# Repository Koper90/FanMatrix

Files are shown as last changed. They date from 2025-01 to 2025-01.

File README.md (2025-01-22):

# FanMatrix



This board was created out of necessity, as I found myself needing more fan and thermistor ports for my own 3D printers. It's perfect for expanding cooling systems, temperature monitoring, and fan control setups in Klipper-based 3D printers, with minimal additional cost.

This repository contains the design files and firmware for a low-cost PCB-based port expander. It is specifically designed to run Klipper firmware for controlling cooling and sensor peripherals in 3D printers. The board takes in 24V DC and steps it down to 12V and 5V, each capable of delivering up to 1A of current, making it ideal for controlling fans and sensors.

### Key features include:

- 5 PWM fan outputs with selectable fan voltage via jumper (12V or 5V).
- 4 tacho fan outputs to monitor fan RPM with selectable fan voltage via jumper (12V or 5V).
- 9 thermistor inputs for temperature monitoring.
- STM32 32-bit ARM Cortex M0 microcontroller for efficient processing and control.
- A serial connection via USB-C allows easy communication with external systems.
- 3 additional ports available for expansion with extra peripherals.

Designed to run Klipper firmware for seamless integration with 3D printing systems.
Designed with low cost in mind for accessible integration into projects.

### Mounting

Mounts are located in the CAD folder.

### Connectors

All the connectors are JST PH 2.54.

### Interactive BOM

[FanMatrix BOM](https://htmlpreview.github.io/?https://github.com/Koper90/FanMatrix/blob/main/KiCad/ibom.html)

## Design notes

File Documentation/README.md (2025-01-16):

This document outlines the common features of the board that you are likely to use.

## Main Features
annotely_image (1)

The board operates on a 24V DC power supply and includes the following inputs and outputs (I/O):

- 5 PWM 4-pin fan outputs
- 4 ground-switched fan outputs with tacho feedback
- 9 thermistor inputs for temperature sensing

Each fan output is equipped with a voltage selector, allowing the user to choose between 5V, 12V, or 24V DC depending on the requirements of the connected fan.

The board also features a fuse slot, and it is recommended to use a 3 AMP automotive fuse to protect the circuit from overcurrent conditions.

## Voltage selector for fan outputs

To set the appropriate voltage for the fan output, use the jumper and place it in the correct position on the voltage pin selector. The board is marked with the available voltages. For example, in the image below, putting the jumper in the orientation shown within the red rectangle selects 24V for the fan output.

Ensure that the jumper is securely placed and matches the required voltage for your device before powering on the system.


## LED indicator

LED indicators for the 5V and 12V DC busbars, which are used to verify whether 5V and 12V power is available.

## Boot and reset keys

This boot button needs to be pressed to put the board in DFU mode to flash it with the klipper firmware. The board will show up as "Device in DFU Mode" to ```lsusb``` and then should show up in ```dfu-util --list```

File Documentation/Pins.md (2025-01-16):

### Fan and Thermistor Pin Assignments for FanMatrix Board

#### 4-Pin PWM Fan Pin Assignments
The following pins are used for controlling 4-pin PWM fans. Each fan has a designated PWM signal and a tachometer (TACHO) pin:

- **FAN 1**:  
  - PWM: `PB10`
  - TACHO: `PB11`

- **FAN 2**:  
  - PWM: `PB1`
  - TACHO: `PB2`

- **FAN 3**:  
  - PWM: `PB0`
  - TACHO: `PA7`

- **FAN 4**:  
  - PWM: `PA6`
  - TACHO: `PA5`

- **FAN 5**:  
  - PWM: `PA4`
  - TACHO: `PA3`

#### 3-Pin Fan Pin Assignments
These pins are used for 3-pin fans, where PWM is tied to GND, and a tachometer is provided for speed monitoring:

- **FAN 1**:  
  - PWM: `PA0`
  - TACHO: `PA1`

- **FAN 2**:  
  - PWM: `PB12`
  - TACHO: `PA2`

- **FAN 3**:  
  - PWM: `PB15`
  - TACHO: `PB14`

- **FAN 4**:  
  - PWM: `PA9`
  - TACHO: `PA8`

#### Thermistor Pin Assignments
The thermistor inputs are assigned to the following pins:

- **Therm0**: `PB9`
- **Therm1**: `PB8`
- **Therm2**: `PB7`
- **Therm3**: `PB6`
- **Therm4**: `PB5`
- **Therm5**: `PB4`
- **Therm6**: `PB3`
- **Therm7**: `PA15`
- **Therm8**: `PA14`

### Usage Notes
- Ensure that all connections are properly made according to the above pin assignments.
- The 4-pin fans use separate PWM and tachometer pins for precise speed control and monitoring.
- For 3-pin fans, PWM signals are tied to GND, so speed is controlled by manipulating GND, but tachometer readings are still available for monitoring.
- Thermistor inputs can be used to monitor temperature readings for various zones or components.

This pin documentation should serve as a reference for configuring and wiring the FanMatrix board.

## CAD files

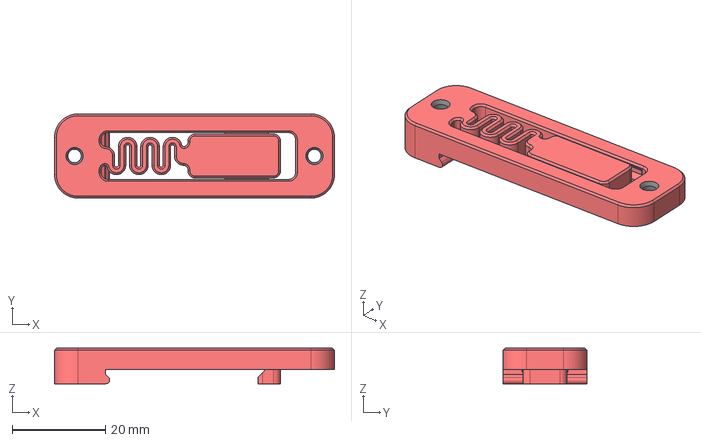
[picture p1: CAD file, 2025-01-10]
CAD/Stiffer_DinMount_M3.stp
59.9 x 18.0 x 7.60 mm

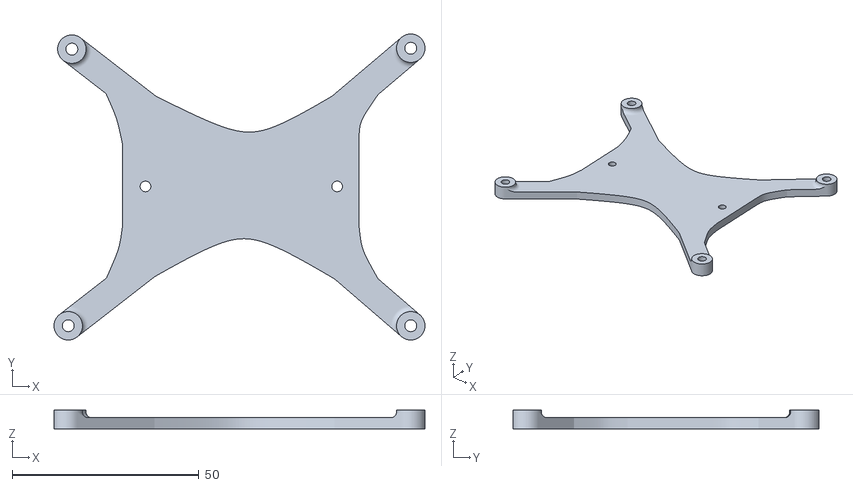
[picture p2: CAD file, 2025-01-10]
CAD/FanMatrix_Mount.stl
99.3 x 81.9 x 5.00

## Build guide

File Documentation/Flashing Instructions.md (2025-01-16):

Here’s a summarized and clarified version of the flashing instructions for ease of use:

---

### Flashing the Board for Klipper

1. **Connect Hardware**  
   - Attach the board to the Raspberry Pi via USB.  
   - Ensure either the **5V jumper** is connected or **24V power** is supplied to the board.

2. **Access Raspberry Pi**  
   - Connect to the Raspberry Pi via SSH.

3. **Enter DFU Mode**  
   - Press and hold the **Boot** button.  
   - While holding **Boot**, press and release the **Reset** button.  
   - Release the **Boot** button. The board should now be in DFU mode.

4. **Verify DFU Mode**  
   - Run `lsusb` to ensure the STM32 device is listed in DFU mode.  
   - Run `dfu-util --list` and note the device identifier in `[xxxx:yyyy]`.

5. **Prepare Klipper Firmware**  
   - Navigate to the Klipper directory:  
     ```bash
     cd ~/klipper
     ```
   - Configure the build with `make menuconfig`:
     klipper_config

     - Ensure the settings match the provided configuration screenshot.
     - Press **Q** to exit and save changes.

6. **Build the Firmware**  
   - Clean the environment:  
     ```bash
     make clean
     ```  
   - Flash the firmware using the device identifier from Step 4:  
     ```bash
     make flash FLASH_DEVICE=xxxx:yyyy
     ```

7. **Finalize the Flashing**  
   - Press the **Reset** button to restart the board.

8. **Verify the Serial Connection**  
   - Run the following command to list serial devices:  
     ```bash
     ls /dev/serial/by-id/*
     ```  
   - Look for a device similar to:  
     ```
     /dev/serial/by-id/usb-Klipper_stm32f072x6...
     ```

9. **Update Configuration**  
   - Copy the serial port name (e.g., `/dev/serial/by-id/usb-Klipper_stm32f072x6...`).  
   - Add it to the `[FanMatrix mcu]` section in your Klipper configuration file.

10. **Include Example Config**  
    - Copy the example configuration file into the same directory as `printer.cfg`.  
    - Add the following line to the end of `printer.cfg`:  
      ```
      [include FanMatrix.cfg]
      ```

---

Your board should now be ready to use with Klipper! 🚀

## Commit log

2025-01-10 Create CAD
2025-01-10 Delete CAD
    Mistake
2025-01-13 Update and rename ibom.html to BOM/ibom.html
